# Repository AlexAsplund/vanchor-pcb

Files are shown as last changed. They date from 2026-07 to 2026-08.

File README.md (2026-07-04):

# Vanchor PCBs (helm v4.2 + thrust driver v1.1)

Carrier PCB for the [vanchor-ng](../vanchor-ng) trolling-motor autopilot:
an **Orange Pi Zero 3** (autopilot computer) + **Raspberry Pi Pico 2**
(real-time motor controller, I²C slave) on one **125×95 mm 2-layer board
(standard 1 oz)**. Thrust power lives on the companion **thrust-driver
board** cabled to J13 (any IBT-2/BTS7960-class driver also works); the
steering-servo bridge is on board. **12 V-only** (car battery, 14.4 V
charging) — the 5 V rail comes from an XL4015 buck module soldered on as a
daughterboard (U5). Full system diagrams: **`docs/architecture.md`**.

```mermaid
graph LR
    BATT[("12V battery")] -->|"J16, F1 10A, rev-FET"| VIN["VIN"]
    BATT ==>|"fat cable + ANL fuse"| TD["thrust driver board<br/>(J13 8-wire cable)"]
    VIN --> U5["U5 XL4015 buck 5V"] --> SBC["Orange Pi Zero 3 / RPi<br/>(J1 ribbon) + screen + fan"]
    VIN --> SRV["2x BTN8982TA servo bridge"] -->|"J22"| SM["12V worm servo"]
    SBC <-->|"I2C3"| PICO["Pico 2 @0x42"]
    PICO -->|"GP12-15 PWM"| TD --> M(("trolling motor"))
    PICO --> SRV
    SM -->|"AS5600, J11"| PICO
    SBC -.->|"WiFi"| TAB["tablet"]
    HWT["HWT901B AHRS"] -->|"J3 UART5"| SBC
    PICO <-->|"can2040 + J12 xcvr + J5"| N2K[("NMEA2000")]
```

*[static SVG](docs/diagrams/readme-overview.svg) — full diagram set: `docs/architecture.md`*

Cost history: v1/v2 carried an on-board 800 W H-bridge; ten documented
cost-optimization passes (see `docs/cost-optimization-log.md`) brought a
12 V build from ~$111 to **~$41 per assembled board** (~$35 parts + ~$6 PCB).
The v2 on-board-bridge design remains available at git tag/commit `bf91c4a`.

## NMEA2000 / CAN provision (helm board)

CAN lives on the Pico 2 (can2040 PIO CAN on GP18/GP19, 250 kbit/s for
NMEA2000). Plug a 3.3 V CAN transceiver module (Waveshare SN65HVD230) onto
J12 with four jumper wires: pin 1 = 3V3, pin 8 = GND, pin 6 = GP18 -> CTX,
pin 7 = GP19 -> CRX. The N2K drop cable's CAN_H/L land on the module's
screw terminal; its power/shield conductors land on J5 (V+ / GND / SHIELD).
R41 (0R, DNP): fit to power the backbone from the battery input - add an
inline 2-3 A fuse in the drop cable if you do. R42 (0R, DNP): bond shield
to GND only if the network isn't grounded elsewhere.

## Boards

- `boards/helm/` — the helm/carrier board (Orange Pi Zero 3 *or* Raspberry Pi + Pico 2, servo
  bridge, XL4015 buck daughterboard, PWM output header J13).
- `boards/thrust-driver/` — 12-24 V trolling-motor H-bridge (2-4× BTN8982TA),
  connects to helm J13 with a straight 8-wire cable. See its README for the
  base (~30 A) vs high-power (~50 A) variants and the solder-lane
  reinforcement technique.

## Repository layout

| Path | Content |
|---|---|
| `boards/helm/` | KiCad 10 project (schematic, board, custom symbols/footprints) |
| `boards/helm/sheets/*.py` | Net-spec sources — the schematic is **generated** from these |
| `boards/helm/scripts/` | Generators + gates (`build_sch.sh`, `build_board.py`, ERC/DRC helpers) |
| `boards/helm/fab/` | Gerbers, drill, BOM — upload these to PCBWay/JLCPCB |
| `boards/thrust-driver/` | Companion H-bridge board (own README, sheets, scripts, fab) |
| `docs/architecture.md` | **System diagrams**: WiFi/tablet, NMEA0183+2000, HWT901B, control loop |
| `docs/cost-optimization-log.md` | The 10 cost passes and their effect |
| `docs/superpowers/` | Design spec + implementation plan |
| `.claude/skills/` | kicad-happy review skills (vendored) |

## Regenerating the design

```sh
docker compose up -d                 # KiCad 10 container (GUI at https://localhost:3001)
./boards/helm/scripts/build_sch.sh      # specs -> .kicad_sch + ERC
docker exec vanchor-kicad kicad-cli sch export netlist --format kicadsexpr \
    -o /config/vanchor-pcb/boards/helm/vanchor-helm.net /config/vanchor-pcb/boards/helm/vanchor-helm.kicad_sch
docker exec -e BASE_GND=0 vanchor-kicad python3 /config/vanchor-pcb/boards/helm/scripts/build_board.py
# route with freerouting-1.9 (see git history for the exact docker command),
# then: docker exec vanchor-kicad python3 /config/vanchor-pcb/boards/helm/scripts/import_routes.py
```

## Connector map

| Ref | Label | Wire to |
|---|---|---|
| J16 | BATT 12V | battery + / − (board logic + servo supply; ≥1.5 mm²) |
| J13 | THRUST DRV | external driver, IBT-2 pin order: **1 RPWM · 2 LPWM · 3 R_EN · 4 L_EN · 5 R_IS · 6 L_IS · 7 VCC(5V) · 8 GND** |
| J22 | SERVO MOTOR | 12 V worm gearmotor of the steering servo |
| U5 | XL4015 BUCK | the module solders ON: pins into its 4 corner terminals, spacers, into the slotted pads (set 5.1 V first!) |
| J1 | OPI Z3 26-PIN | male header → 26-way 1:1 IDC ribbon (original-RPi style) to the Zero 3 |
| J11 | AS5600 | 4-wire cable into servo housing: 3V3 GND SDA SCL (≤1 m, twisted) |
| J3 | UART5 | **HWT901B AHRS** / GPS / NMEA0183-TTL (3V3 TTL, PH2/PH3; `uart5` overlay; wiring in `docs/architecture.md`) |
| J4 | UART2 | second serial device (PC5/PC6; enable `uart2` overlay; swap TX/RX at the JST if silent) |
| J8 | I2C3 spare | I²C sensors (bus shared with Pico link — keep short) |
| J10 | AUX 5V | fused 5 V for a screen or accessory |
| J9 | FAN + HALL | pin 1-2: 5 V fan; pin 3: **steering-zero hall switch** (A3144-class open-collector, magnet at servo center; 10 k pullup to 3V3 + RC on board, reads on Pico GP0) |
| J5 | NMEA2000 PWR | N2K drop-cable V+ / GND / SHIELD (CAN_H/L go to the transceiver module) |
| J2 | SBC2 | second SBC port: same 26-pin bus as J1, classic RPi positions — fit ONE SBC only (DNP) |
| J12 | PICO UTIL | spare Pico I/O; carries the CAN transceiver hookup (pins 1/8/6/7, see NMEA2000 section) |

Battery→motor power wiring (fat cables, ANL fuse) goes to the **thrust
driver board**, not to this board.

## Mechanical

- The Zero 3 (pre-soldered pins-up variant) connects via a **standard
  26-way 1:1 IDC ribbon** (~$1.50, original-Raspberry-Pi style) from its
  header to J1 — match pin 1 (marked) on both ends. The module mounts
  wherever suits the enclosure; the two spare M3 holes near J1 can carry a
  small mounting plate.
- The module is powered through the ribbon 5 V pins — do **not** also plug
  USB-C power. Keep the ribbon short (≤15 cm) — it carries I²C and the
  module's supply. The 3.3 V for the JST headers comes from the module's
  regulator (keep attached loads under ~200 mA total).
- J1 pins 14 & 20 and J2 pin 9 are deliberately NC (each connector keeps
  at least three other ground pins; the header escape routing owns those
  corridors).
- J2/J12 are DNP debug breakouts whose outlines slightly overlap — populate
  at most one, or use a right-angle header on J12.
- 4× M3 corner mounting holes. No heatsink needed on this board.

## Power & safety notes

- F1 (10 A mini blade) fuses everything on this board. The thrust path is
  fused externally at the battery per your driver's rating.
- **Thrust**: GP12-15 drive the external driver's RPWM/LPWM/R_EN/L_EN at
  3.3 V (fine for BTS7960-class VIH ≈ 2.5 V). 100k pull-downs on both EN pins
  keep the driver disabled when the Pico is absent/in reset. R_IS/L_IS are
  mixed (2× 1k), loaded (20k), filtered and BAT54S-clamped into Pico ADC1.
- **Servo bridge**: 2× BTN8982TA (built-in protection), fed battery-direct
  from protected VIN. Board plumbing is sized for ~5 A continuous /
  ~10 A peak servo current (F1, terminal blocks, track widths).
- Telemetry: thrust current via the driver's IS pins (ADC1), servo current
  (ADC0), battery voltage (ADC2).
- Reverse polarity: IRF9540N high-side FET; SMCJ18A TVS (12 V clamp);
  2× 470 µF/25 V bulk.
- The buck module (U5) mounts as a daughterboard: solder 4 pins into the
  XL4015's corner terminals, slide 5-8 mm spacers on, solder into the
  slotted pads (slots absorb vendor hole-grid variance; buy the common 54×23 mm module
  variant (nominal 49×18 mm hole grid) — the smaller 51×26 mm variant has a
  different grid that may not fit; verify against your module). Set 5.1 V and load-test at 4 A BEFORE
  soldering it in. R20/R21/D10/D11 sit under the module's edge — fit them
  first.
- Firmware contract: I²C slave 0x42, reg 0x00 CMD {pwm u8, dir u8, steer i8},
  reg 0x10 STATUS {angle f32, ok u8, wrap i8, state u8, vbat_mV u16,
  isense u16}; 800 ms watchdog → thrust 0, steering holds (worm self-locks).
  Pin deltas vs v2: thrust on **GP12=RPWM GP13=LPWM GP14=R_EN GP15=L_EN**;
  GP16/GP26 freed.
- Zero 3 side: I²C3 (`i2c3` overlay) for the Pico link, `uart2`/`uart5`
  overlays for the JSTs; Pico RUN on PC11, SWD reflash via PC15 (SWDIO) /
  PC14 (SWCLK) — openocd sysfsgpio/libgpiod driver on the H618.

## Bring-up checklist

1. Visual + continuity: VIN↔GND, 5V↔GND, 12V↔GND not shorted.
2. No Zero 3/Pico fitted. Feed 12 V into J16: VIN LED lights; verify the
   buck module outputs 5.0-5.2 V on J1 pins 2/4.
3. Fit the Pico only (no Zero 3): flash test firmware over USB, check I²C
   pull-ups, exercise LED_STAT.
4. Plug in the Zero 3 (pin 1 to the marked corner!). `i2cdetect -y 3` →
   device at 0x42.
5. Connect AS5600 cable: Pico reads angle; rotate servo shaft by hand.
6. Servo closed-loop test with the gearmotor on a bench supply.
7. Connect the external thrust driver to J13, small test motor on its
   outputs: verify PWM, direction, the EN failsafe (reset the Pico mid-run →
   driver must drop out) and IS telemetry on ADC1.
8. Only then wire the real trolling motor through the external driver.

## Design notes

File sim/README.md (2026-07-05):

# Analog chain simulations (ngspice)

Repeatable SPICE verification of the boards' critical analog paths.
Run: `docker run --rm -v $PWD/sim:/sim -w /sim debian:bookworm-slim sh -c "apt-get update -qq && apt-get install -y -qq ngspice gnuplot-nox && for f in *.cir; do ngspice -b $f; done && gnuplot plots.gp"`
(Digital parts — SBC, Pico, buck module, CAN — are not SPICE-able; this
suite covers every analog conditioning chain instead.)

## Results (2026-07-06, ngspice-39)

| Chain | Deck | Result | Verdict |
|---|---|---|---|
| Thrust IS telemetry (driver 1k loads → helm mix → ADC1) | `is_telemetry.cir` | 10 A → 0.21 V, 30 A → 0.63 V, 50 A → 1.05 V at the ADC (linear). **IS fault (4.4 mA): 2.10 V — inherently safe, clamp never conducts** (the mix/divider itself protects). | PASS |
| VBAT sense (47k/10k + BAT54S) | `vbat_sense.cir` | 12.6 V → 2.21 V. **40 V load-dump: ADC node clamps at 3.53 V pk** (< 3.6 V abs max), 0.42 mA into the 3V3 rail. | PASS |
| Reverse-polarity P-FET (IRF9540N + 12 V zener) | `reverse_fet.cir` | Forward 14.4 V @ 2.4 A: V(gs) −11.9 V (zener clamped), mV-class drop. **Reversed battery: load node 0 V** (fully blocked). | PASS |
| Hall zero input (10k pullup, 100n, 1k series) | `hall_input.cir` | Fall 3 µs (crisp edge for the zero index); **rise ≈ 1.3 ms** (10k·100n+cable). Fine for calibration-speed sweeps; fit C24 = 10 n if a fast index is ever needed. | PASS (note) |
| Servo IS telemetry (1k load, 10k+100n, clamp → ADC0) | `servo_is.cir` | 5 A → 0.22 V, 10 A stall → 0.44 V. Fault: 3.48 V clamped, 83 µA into 3V3. Bandwidth ≈ 160 Hz (see `servo_bw.svg`). | PASS |

Plots: `is_transfer.svg`, `vbat_dump.svg`, `hall_wave.svg`, `servo_bw.svg`.

## Firmware-relevant numbers

- ADC1 thrust scaling: **≈ 21 mV/A** at the pin (0.63 V @ 30 A) — use this,
  not a naive kILIS×1k calc (the helm mix divides by ~2.1).
- ADC0 servo scaling: **≈ 44 mV/A** (0.22 V @ 5 A).
- ADC2 battery: V(bat)·0.1754 (2.53 V @ 14.4 V).
- Hall GP0: falling edge is the index (3 µs); debounce ≥ 2 ms on release.

## Model caveats

Generic level-1 PMOS and simple diode models (BAT54/BZX85C12 parameters
approximated from datasheets). Good for topology/range verification, not
for mV-exact drops — the real IRF9540N forward drop is ~0.3 V at 2.4 A
(R_DS(on) 117 mΩ), which changes nothing qualitatively.

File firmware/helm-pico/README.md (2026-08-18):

# vanchor helm-board Pico 2 firmware

One RP2350 replaces both vanchor-ng Arduinos: **engine** (thrust, via the
companion BTN8982 driver board on J13) and **steering** (on-board BTN8982
bridge, AS5600 azimuth encoder, hall zero index) speaking the vanchor-ng
line protocol **unchanged** on two equivalent transports:

- **USB-CDC** — plug-compatible with the existing Pi stack, zero code changes.
- **I²C slave 0x42** on the SBC ribbon — the same bytes through a small
  FIFO register map, so the boat needs no USB cable. Wire spec + a complete
  Pi-side implementation guide: **`docs/I2C-TUNNEL.md`** (the Pi side needs
  one new transport class in vanchor-ng; nothing above it changes).

NMEA2000 (GP18/19) is deliberately not included yet.

## Protocol (the contract)

Vendored verbatim from vanchor-ng in `vendor/` (see `vendor/README.md`):

| Direction | Line | Notes |
|---|---|---|
| Pi → Pico | `CMD <pwm> <dir> <steer> [<seq>]*HH` | combined thrust + steering (the default) |
| Pi → Pico | `STEERD <deg> [<seq>]*HH` | v2.1 degrees-native steering |
| Pi → Pico | `THRUST <pwm> <dir> [<seq>]*HH` | split thrust channel |
| Pico → Pi | `A <angle_deg> <ok> <wrap_pct> <seq>*HH` | ~10 Hz steering feedback |
| Pico → Pi | `E <pwm> <dir> <state> <seq>*HH` | ~5 Hz engine status (`RUN/SOFTSTART/REVDELAY/FAILSAFE`) |

CRC-8 (`*HH`) on every line, both directions; CRC-less commands are rejected
(build with `-DVANCHOR_REQUIRE_CRC=0` to tolerate an old Pi). `<steer>`
±100 maps to ±180° (`STEER_FULL_SCALE_DEG`), soft endstops at ±360°
(`STEER_RANGE_DEG`) — identical numbers to `steering.ino`.

**Pi configuration**: point `motor_port` at this board's CDC device, e.g.

```yaml
hardware:
  motor_port: /dev/serial/by-id/usb-Raspberry_Pi_Pico*-if00   # Pico 2 enumerates as "Pico 2"
```

(baud is ignored on CDC; leave `steering_port`/`thrust_port` blank so the
combined `SerialMotorController` drives both axes through this one port.)

## Behaviour

- **Thrust** mirrors `engine.ino`: 1.0/s throttle slew, 1000 ms reverse
  dead-time interlock (must rest at zero before a direction flip), watchdog
  failsafe slews to zero without flipping. Output is the J13 bridge
  (GP12/13 PWM, GP14/15 enables) with the **current-adaptive PWM schedule**
  from `boards/thrust-driver/README.md`: 16 kHz when quiet, stepping down to
  2 kHz at full current (2 A hysteresis), retuned glitch-minimal.
- **Steering** mirrors `steering.ino`: same PID (6.0/0.8/0.6), deadband
  1.2°, stiction floor, stall detection (position + optional current), hold
  on watchdog loss (the worm self-locks). Feedback is the AS5600 on I2C1,
  unwrapped to a continuous multi-turn angle; the **hall index on GP0**
  re-zeros the angle absolutely every time the head passes centre — set
  `CONF enc.hall_deg` if your magnet isn't at dead-centre.
- **Safety chain**: 800 ms protocol watchdog → safe state; 2 s hardware
  watchdog → reboot; both bridges held disabled until the first valid
  command, and the board's 100 k pulldowns keep them disabled whenever the
  Pico is dead, rebooting or being reflashed.
- **Telemetry**: THR_IS / SERVO_IS / VBAT are sampled and filtered every
  tick (used for the PWM schedule and stall trip). Scale constants in
  `include/board.h` carry CALIBRATE notes — verify against a clamp meter.

## Runtime configuration (CONF)

Every tuning value in `include/board.h` below the "steering tuning" line is
a **default**, not a constant: the live values sit in a config struct you
can change over the same serial port, and optionally persist to the last
4 kB sector of the Pico's flash. Commands follow the normal line rules
(CRC-8 `*HH` suffix required unless built with `VANCHOR_REQUIRE_CRC=0`);
they do **not** feed the 800 ms motor watchdog and do not participate in
the heartbeat, so config chatter can never keep an otherwise-dead link
looking alive.

| Command | Effect |
|---|---|
| `INFO*HH` | identity / versions / health snapshot (`I ...` lines) |
| `CONF <key> <value>*HH` | set in **RAM only** — reverts on reboot |
| `CONFW <key> <value>*HH` | set in RAM **and** persist *that one key* to flash |
| `CONFSAVE*HH` | persist the **whole active config** to flash |
| `CONFDUMP*HH` | list every key: `C <key> <ram_value> <stored_value>` |

`INFO` (`INFO*58` on the wire) answers six `I` lines — firmware git version, protocol
settings, config/flash state, I²C tunnel state, uptime/VBAT/angle:

```
> INFO*58
< I fw v1.2-3-gabc123 board helm-4.2 mcu pico2*..
< I proto 2.1 crc 1 wdog 800*..
< I conf 1 keys 23 flash stored*..        ("defaults" = no valid image)
< I i2c 0x42 v1 active 0*..
< I up 7423 vbat 12.6 ang -3.2 fb 1*..
< I end 5*..
```

Replies to all of these are `C ...`/`I ...` lines (CRC'd), which the Pi's
lenient feedback parsers ignore by design:

```
> CONF steer.kp 8.5*85
< C ok steer.kp 8.5*..          RAM updated
> CONFW enc.invert 1*05
< C wrote enc.invert 1*..       RAM + flash (or "C clean" if flash already had it)
> CONFSAVE*9C
< C saved*..                    whole config written (or "C clean" — no diff)
< C err key <k> / C err range <k> / C err ratelimit / C err flash
```

Semantics worth knowing:

- **`CONFW` writes through only its own key.** The stored image is
  read-modify-written for that single key, so other *temporary* `CONF`
  experiments in RAM stay temporary. `CONFSAVE` is the opposite: it
  snapshots everything currently active.
- **Diff guard**: before any write the firmware serializes the would-be
  image and byte-compares it with the sector. Identical → no erase, no
  program, reply `C clean`. Saving an unchanged config costs zero wear.
- **Rate limit**: writes are refused (`C err ratelimit`) within 2 s of the
  previous write — a stuck script cannot chew through the flash.
- **Validation**: each key has a hard range (`src/config.h`); out-of-range
  or non-numeric values are rejected wholesale (`C err range`), never
  clamped, so a typo can't half-apply. The same validation runs when
  loading from flash, so a corrupted value can never boot into the loop.
- **Integrity**: the stored image is magic + version + count + CRC32. Any
  mismatch at boot → factory defaults (fail-safe, visible in `CONFDUMP`).
  The layout is append-only: new keys go at the end, so an image saved by
  older firmware still loads with defaults for the missing tail. A
  `CONF_VERSION` bump discards stored config entirely.

Keys (see `src/config.h` for ranges): `steer.kp/ki/kd/ilim/db/minpwm/
maxpwm/range/fullscale/stall_err/stall_move/stall_ms/stall_a/recenter`,
`enc.invert/gear/hall_deg`, `thr.slew/rev_ms/hyst_a`,
`cal.thr_vpa/srv_vpa/vbat`.

All of this works identically over the I²C tunnel — `CONF*` lines and
`C ...` replies are transport-agnostic (see `docs/I2C-TUNNEL.md` §3 for the
one nuance: drain promptly after `CONFDUMP`, its ~750 B burst is most of
the tunnel's TX FIFO).

Generating the CRC for hand-typed commands: any of the OK vectors in
`vendor/protocol_vectors.txt` shows the format; quickest is
`python3 -c "import sys;l=sys.argv[1];c=0
for ch in l.encode():
 c^=ch
 for _ in range(8):c=((c<<1)^7)&0xFF if c&0x80 else (c<<1)&0xFF
print(f'{l}*{c:02X}')" 'CONF steer.kp 8.5'` — or build the bench binary with
`VANCHOR_REQUIRE_CRC=0` and skip suffixes entirely.

### ⚠ Why writing to flash is rationed

The RP2350 executes code from external **NOR flash** (W25Q-class). That
matters twice:

1. **Wear.** NOR flash erases in 4 kB sectors and each sector is only
   rated for ~100 000 erase cycles. There is **no wear levelling** in this
   scheme — every save erases the *same* sector. 100 k sounds like a lot:
   saving once a minute, around the clock, kills the sector in ~10 weeks;
   a bug that calls `CONFSAVE` at the 10 Hz command rate destroys it in
   **under 3 hours**. Hand-tuning sessions are harmless (even 50 saves a
   day is 5+ years), but *never* automate periodic saves. The diff guard
   and the 2 s rate limit are backstops, not an invitation — a value that
   genuinely changes every save (e.g. persisting a live measurement) would
   sail straight through the diff guard. Past the rating, sectors fail as
   silent bit-rot; the CRC turns that into "boots with defaults", which is
   safe but means your calibration silently vanishes.
2. **The write stalls the firmware.** During the sector erase + program
   (tens of milliseconds) the flash chip cannot serve code, so the
   firmware runs the write from RAM with **interrupts off**: the control
   loop freezes, hall edges are missed, USB traffic queues. The PWM
   hardware keeps running at the last duty, and both watchdogs comfortably
   cover the pause, but the steering PID is open-loop for that window —
   so save at the dock, not mid-manoeuvre. A power cut exactly during the
   erase window corrupts the sector; the CRC catches it at next boot and
   you fall back to defaults (another reason `CONFDUMP`'s stored column
   exists: verify after saving).

Practical rule: tune with `CONF` (free, unlimited), persist once with
`CONFSAVE` when the boat feels right, confirm with `CONFDUMP`.

## Building

Requires the [pico-sdk](https://github.com/raspberrypi/pico-sdk) **2.0+**
(unconditionally — `pico_i2c_slave` first shipped in 2.0.0) and
`gcc-arm-none-eabi`:

```sh
export PICO_SDK_PATH=~/pico-sdk        # or -DPICO_SDK_FETCH_FROM_GIT=on
cmake -B build -DCMAKE_BUILD_TYPE=Release
cmake --build build -j
# -> build/vanchor_helm_pico.uf2 / .elf
```

CMake options: `-DPICO_BOARD=pico` targets an original RP2040 Pico (see
below); `-DVANCHOR_REQUIRE_CRC=0` builds the CRC-tolerant bench variant
(this is a real cache option wired to the compiler — no CXX_FLAGS tricks).

## Bare Pico / DIY build (no vanchor PCB)

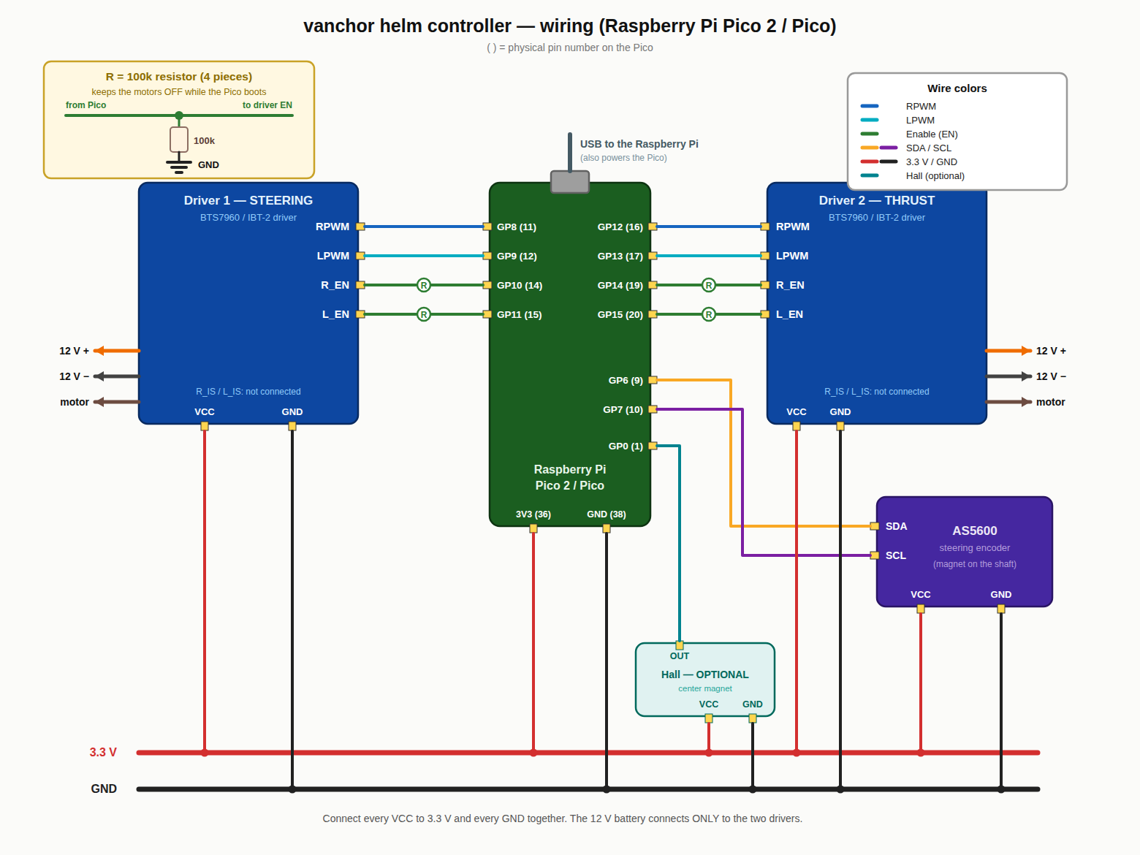
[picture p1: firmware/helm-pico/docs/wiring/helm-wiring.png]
Wiring diagram: Pico 2 with two BTS7960 drivers, AS5600 encoder and optional hall sensor


*( ) = physical pin number on the Pico. The yellow box shows how each of the
four 100 k EN pulldowns connects. Generated by
[`docs/wiring/gen_wiring.py`](docs/wiring/gen_wiring.py) — edit that, not the
image.*

The firmware runs on a plain **RP2040 Pico or Pico 2** with two IBT-2 /
BTS7960-style H-bridge modules and an AS5600 breakout — the PWM tick is
derived from `clk_sys` at boot, so both chips get correct frequencies.

```sh
cmake -B build -DPICO_BOARD=pico \
  -DCMAKE_CXX_FLAGS="-DPIN_LED_STAT=25"   # onboard LED on a bare Pico
```

Every pin and default in `include/board.h` is `#ifndef`-guarded, so override
whatever differs from the PCB the same way (`-DPIN_SRV_RPWM=2 ...`). Default
wiring (BTS7960 naming): servo bridge RPWM/LPWM = GP8/GP9, R_EN/L_EN =
GP10/GP11; thrust bridge RPWM/LPWM = GP12/GP13, R_EN/L_EN = GP14/GP15;
AS5600 SDA/SCL = GP6/GP7 (breakouts carry their own pull-ups); optional hall
zero on GP0 (internal pull-up enabled); optional SBC I2C tunnel on GP4/GP5.

Two hardware notes that the firmware cannot cover for you:

- **Add a physical ~100 k pulldown on all four EN pins.** During reset,
  BOOTSEL and reflash the Pico's pins float, and IBT-2 modules do not
  guarantee their own pulldowns — without resistors the bridges can float
  enabled while the firmware is not running. The vanchor PCB has them; a
  breadboard build must too.
- BTS7960 current sense scales differently from the PCB's BTN8982
  (kILIS ≈ 8500 vs 22700): calibrate `cal.thr_vpa` / `cal.srv_vpa` over
  serial (`CONF`) against a clamp meter, or leave current-based stall off
  (default) and skip the IS pins entirely.

## Flashing

- **First time / no debugger**: hold BOOTSEL, plug USB, copy the `.uf2`.
- **In-circuit (assembled boat)**: SWD over the ribbon from the SBC —
  SWCLK/SWDIO land on Zero 3 pins 16/18 (PC15/PC14), RUN on pin 12:
  `openocd -f interface/linuxgpiod.cfg -f target/rp2350.cfg` (`rp2040.cfg`
  for an original Pico; pin mapping in `docs/HANDOFF.md`). Never needed for
  normal operation.

## Bring-up checklist

1. Bench-power the helm board, no props, `screen /dev/ttyACM0`.
2. You should see `A ...` at 10 Hz and `E 0 F RUN -1*..` at 5 Hz. `ok` will
   be `1` only with the AS5600 magnet in range.
3. Type `CMD 0 F 0*DC` — the enables assert (bridge LEDs / 5 V on J13.7).
4. `CMD 60 F 0*..` (compute a CRC with `tests/`, or build with
   `VANCHOR_REQUIRE_CRC=0` for the bench) — thrust ramps softly; stop
   commanding — after 800 ms the `E` state shows `FAILSAFE` and it ramps out.
5. Swing the head by hand past centre — the hall edge re-zeros `A`'s angle.
6. `STEERD 10.0*..` — the servo drives; verify +deg = starboard, else send
   `CONF enc.invert 1` (encoder) and/or swap the servo motor leads (drive).

## Tests

`make -C tests` — host-compiles the **exact** shipped headers and replays
the golden `protocol_vectors.txt` through the real accept/parse path (both
CRC modes), round-trips outbound `A`/`E` CRCs, and unit-tests the reverse
gate, slew, failsafe states, PID direction/deadband/stall and the multi-turn
unwrap. CI-friendly: exits non-zero on any failure.

## Layout

```
CMakeLists.txt, pico_sdk_import.cmake   build glue (PICO_BOARD=pico2)
include/board.h                          pin map + tuning defaults
src/main.cpp                             transports, sensors, output stages
src/control_logic.h                      hardware-free control cores
src/config.h                             CONF keys, validation, persistence
src/tunnel_core.h, src/i2c_tunnel.*      I2C tunnel (register machine + glue)
src/protocol_ext.h                       THRUST token parser (+ vendored hdr)
vendor/                                  the contract, verbatim from vanchor-ng
docs/I2C-TUNNEL.md                       I2C wire spec + Pi implementation guide
tests/                                   host test suite (no SDK needed)
```

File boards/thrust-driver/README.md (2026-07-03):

# vanchor-thrust — trolling-motor DC driver

95×92 mm 2-layer board. Full H-bridge for a 12–24 V brushed trolling motor,
controlled by the vanchor-helm board over one straight 8-wire cable. Two
build variants share the same PCB:

| Variant | Fit | Continuous current |
|---|---|---|
| Base | U1 + U2 (2× BTN8982TA) | ~30 A (with cable reinforcement, see below) |
| High power | also U3 + U4 + R7 + R8 | ~50 A |

## Cable to the helm board

J1 mirrors helm J13 **pin-for-pin** — crimp a straight 8-wire cable
(0.5–1 mm², keep it under ~2 m, twist RPWM/LPWM with GND spares if longer):

| Pin | Signal | Direction |
|---|---|---|
| 1 | RPWM | helm → driver |
| 2 | LPWM | helm → driver |
| 3 | R_EN | helm → driver |
| 4 | L_EN | helm → driver |
| 5 | R_IS (current sense A) | driver → helm |
| 6 | L_IS (current sense B) | driver → helm |
| 7 | +5V (logic, from helm buck) | helm → driver |
| 8 | GND | — |

The LED (D1) lights when the helm's 5 V arrives — a quick cable check.

## Power wiring

M5 lugs: BATT+ / BATT− on the left edge, MOT A / MOT B on the right.
Use 10 mm² (8 AWG) or thicker cable for the 50 A build. **Fuse the battery
lead externally** (ANL or MIDI, 40 A base / 60 A high power) close to the
battery. There is **no reverse-polarity protection** — double-check
polarity before connecting; reversed battery destroys the BTN8982s.
D2 (SMCJ33A) clamps inductive spikes; the board is 12–24 V only.

## Solder-lane reinforcement (required above ~15 A continuous)

The board is ordered in standard 1 oz copper — cheap, but the copper alone
won't carry 30–50 A. Every power lane (VBAT band + spine, MOT A, MOT B on
top; GND band on the bottom) has an exposed solder lane (no solder mask).
Before first high-power use:

1. Clean the lanes with IPA, apply flux.
2. Tin each lane with a wide tip.
3. Lay 4–10 mm² desoldered copper braid or stripped solid wire along the
   lane and solder it down continuously end-to-end.

With braid on all lanes the base build handles ~30 A continuous, the
high-power build ~50 A. The 202 "solder mask bridge" DRC warnings are these
lanes — intentional.

## Firmware note (high-power variant)

Each BTN8982's IS pin sources I_load/kILIS (~8500). Both devices of a side
feed the **same** 1 k sense resistor, so with U3/U4 fitted the sensed
voltage per ampere stays the same only if the halves share evenly — in
practice treat the effective kILIS as ~22700 (verify datasheet 5.4.7) with U1/U2 only and ~17000 per
device (halved reading) when paralleled. Calibrate `THR_IS` scaling in the
Pico firmware after choosing the variant.

## NMEA2000 smart-node option (v1.1 provision, all DNP)

The board carries unpopulated through-hole provision to become a
standalone NMEA2000 node — same pattern as the helm board:

- **U5** Pico 2 (GP12-15 wired in parallel with J1's RPWM/LPWM/R_EN/L_EN,
  GP26/27 read the IS sense via R12/R13 1k series, GP18/19 run CAN via
  can2040 — identical GPIO map to the helm Pico, so the thrust firmware
  ports directly).
- **U6** SIP-3 5V regulator: R-78E5.0-0.5 for 12V boats; fit the wide-input
  **R-78HE5.0-0.5** on 24V boats (the plain R-78E tops out at 28V in, too
  close to a charging 24V bank).
- **J6** 4-pin CAN header: 3V3 / GND / TX / RX to a Waveshare SN65HVD230
  transceiver module; CAN_H/L go to the module's screw terminal.
- **J7** XH-3 lands the N2K drop cable's V+ / GND / SHIELD. R10 (0R DNP)
  optionally feeds the backbone from VBAT (fuse the drop cable); R11
  (0R DNP) bonds shield to GND at this node only if nowhere else does.

Dumb mode (default): populate nothing, drive via the J1 cable as before.
Smart mode: fit U5 + U6 + R12 + R13 + transceiver, **leave J1
unconnected** (both would drive the same nets), and implement a command
watchdog in the node firmware (hard-stop to neutral if the command PGN
stream halts >300-500 ms). ADC note: in normal operation the IS voltage
across the 1k loads stays under ~2.2V at 50A (kILIS 22.7k), but in FAULT
the IS pin sources mA-class current and the node's only protection is the
R12/R13 series resistance - fit them as 10k (not 1k) when populating the
node, or add BAT54S clamps to 3V3 like the helm board has.

## PWM frequency (firmware guidance)

The BTN8982TA allows up to 25 kHz, but this board fits **51 k slew-rate
resistors** (low-EMI edges, ~1.5 us each), so switching loss — not the
chip rating — sets the practical limit. Loss per edge scales with both
current and frequency; conduction loss at 30 A is only ~6 W, so high-kHz
PWM at high current quickly dominates the thermal budget:

```mermaid
xychart-beta
    title "Switching loss vs PWM frequency (13V, 51k SR edges ~3us total)"
    x-axis "PWM frequency (kHz)" [2, 4, 8, 12, 16, 20, 25]
    y-axis "watts" 0 --> 16
    line "at 30 A" [1.2, 2.3, 4.7, 7.0, 9.4, 11.7, 14.6]
    line "at 10 A" [0.4, 0.8, 1.6, 2.3, 3.1, 3.9, 4.9]
```

*[static SVG](../../docs/diagrams/pwm-loss.svg)*

**Recommended scheme: current-adaptive PWM.** Run high frequency where it
is silent *and* cheap (low current), ramp down as current rises so the
bridge stays efficient exactly when the prop is loud enough to mask the
hum:

```mermaid
xychart-beta
    title "Recommended PWM vs motor current"
    x-axis "motor current (A)" [0, 5, 10, 15, 20, 25, 30, 40, 50]
    y-axis "PWM frequency (kHz)" 0 --> 18
    line [16, 16, 12, 8, 6, 5, 4, 3, 2]
```

*[static SVG](../../docs/diagrams/pwm-schedule.svg)*

Implementation notes (RP2350, applies to the helm Pico driving this board
over J13 and to the on-board smart-node Pico alike):

- **Switch on measured current (IS), not throttle** — switching loss
  scales with amps. Use ~2 A hysteresis, or blend continuously per the
  curve above (nicer: the whine fades instead of stepping).
- **Glitch-free frequency changes**: change the PWM slice's wrap (TOP)
  value and rescale the compare level by the same ratio in the same
  update; both latch at the wrap boundary, so duty is preserved and the
  motor never feels a step.
- **Resolution is never the constraint**: 150 MHz / 16 kHz is still >13
  bits of duty resolution.
- **IS sampling**: if sampling mid-on-time, recompute the sample point
  when the wrap changes — or use the RC-averaged reading scaled by duty
  (frequency-agnostic; the helm's 20k + 100n chain does this).
- If the bridge runs warm at partial throttle, lower the 16 kHz band's
  ceiling (~10 A -> ~6 A) before touching hardware. If you truly need
  15-25 kHz at full current, swap R3/R4 (R7/R8) from 51 k to ~5.1 k —
  ~10x less switching loss, more EMI ringing; they are through-hole for
  exactly this experiment.

## Assembly order

1. SMD: BTN8982s (U1/U2, plus U3/U4 for high power), D2.
2. Resistors: R1–R6, R9 (+ R7/R8 with U3/U4), diode D1.
3. C3/C4 ceramics, C5 film, then C1/C2 electrolytics (mind polarity).
4. Lugs J2–J5, header J1.
5. Solder-lane braid (see above), then bolt to a heatsink/baseplate through
   the two M3 holes with a thermal pad under the BTN tabs for >20 A use.

## Ordering

Same fab spec as the helm board: 2 layers, 1.6 mm FR-4, 1 oz copper,
HASL, 5/5 mil, 0.3 mm min drill, tented vias. Upload
`fab/vanchor-thrust-gerbers.zip`. ~$10-15 for 5 pcs at PCBWay/JLC.

## Design notes / DRC deviations

- `solder_mask_bridge` warnings (~200): intentional exposed solder lanes.
- `pth/npth_inside_courtyard`, `courtyards_overlap`: warnings only, from
  the lug/cap density; verified manually.
- `solder_mask_bridge` is set to *ignore* in the project (the exposed
  solder lanes intentionally span nets' mask apertures).
- The routed .kicad_pcb includes hand-placed link tracks and via-hops for
  the DNP-pair nets (RPWM/LPWM/R_EN/L_EN/R_IS/L_IS between U1/U2 and
  U3/U4) — regenerating the board from `scripts/build_board.py` requires
  re-running freerouting **and** re-applying equivalent patches; treat the
  checked-in board file as the source of truth.

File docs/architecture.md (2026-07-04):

# Vanchor system architecture

How the boards, sensors, networks and the tablet fit together.
(Diagrams are Mermaid — github.com renders them in the file view.
Viewing in a commit diff, the mobile app, or a non-GitHub viewer? Use the
pre-rendered SVGs in `docs/diagrams/`, linked under each diagram.)

## System overview

```mermaid
graph TB
    subgraph BOAT["boat 12V system"]
        BATT[("12V battery")]
    end

    subgraph HELM["HELM BOARD (125x95)"]
        PWR["F1 10A + reverse-FET<br/>+ XL4015 buck 5V (U5)"]
        SBC["Orange Pi Zero 3 / RPi<br/>Linux: vanchor-ng + Signal K"]
        PICO["Pico 2 (RP2350)<br/>real-time motor ctrl, I2C 0x42"]
        SRVBR["servo H-bridge<br/>2x BTN8982TA"]
        XCVR["SN65HVD230<br/>CAN transceiver on J12"]
        PWR --> SBC
        PWR --> PICO
        SBC <-->|"I2C3 (ribbon)"| PICO
        PICO --> SRVBR
        PICO <-->|"GP18/19 can2040"| XCVR
    end

    subgraph THRUST["THRUST DRIVER (95x92)"]
        HBRIDGE["H-bridge 2-4x BTN8982TA<br/>base ~30A / high ~50A"]
    end

    TABLET["tablet / phone<br/>OpenCPN, Signal K web"]
    IMU["HWT901B AHRS<br/>(heading, roll, pitch)"]
    N2K[("NMEA2000 backbone<br/>MFD, GPS, wind, AIS")]
    N183["NMEA0183 device<br/>(GPS puck, AIS rx)"]
    SERVO["12V worm-gear servo<br/>+ AS5600 encoder"]
    MOTOR(("trolling motor"))

    BATT -->|"J16 (1.5mm2)"| PWR
    BATT ==>|"fat cable + ANL fuse"| HBRIDGE
    SBC -.->|"WiFi AP / LAN"| TABLET
    IMU -->|"J3 UART5 TTL"| SBC
    N183 -->|"J4 UART2 (TTL, see note)"| SBC
    XCVR <-->|"CAN H/L + J5 pwr/shield"| N2K
    PICO -->|"J13 -> J1 straight 8-wire"| HBRIDGE
    SRVBR -->|"J22"| SERVO
    SERVO -->|"J11 AS5600 I2C"| PICO
    HBRIDGE ==> MOTOR
```

*[static SVG](diagrams/system-overview.svg)*

Two supply domains, deliberately separate: the helm board takes a fused
1.5 mm² feed for logic + servo (≤10 A), while the motor current
(30–50 A) runs battery → thrust driver → motor on fat lugged cable and
never touches the helm board.

## Software / data flow to the tablet

```mermaid
graph LR
    subgraph SBC["SBC (Linux)"]
        SK["Signal K server"]
        VNG["vanchor-ng autopilot"]
        SK <--> VNG
    end
    subgraph PICO2["Pico 2"]
        FW["motor firmware<br/>watchdog 800ms"]
        GW["N2K gateway (core 1)<br/>can2040 + Actisense framing"]
    end

    HWT["HWT901B @ /dev/ttyAS5"] --> SK
    N183IN["NMEA0183 @ /dev/ttyAS2"] --> SK
    GW -->|"USB CDC or UART<br/>(Actisense NGT-1 emulation)"| SK
    VNG -->|"I2C 0x42: thrust/steer cmd"| FW
    FW -->|"status: angle, currents, vbat"| VNG
    SK -->|"WiFi: Signal K web, TCP 10110<br/>(NMEA0183 over IP)"| TAB["tablet: OpenCPN /<br/>Freeboard / WilhelmSK"]
```

*[static SVG](diagrams/software-dataflow.svg)*

The Zero 3's on-board WiFi runs as an access point (hostapd + dnsmasq) or
joins the boat's network; the tablet needs nothing but a browser or a
chartplotter app pointed at the Signal K/NMEA-over-TCP port.

## HWT901B attitude sensor (heading source)

The WitMotion HWT901B-TTL (9-axis AHRS + barometer, Kalman-filtered
roll/pitch/yaw) connects to **J3 (UART5)** with a 4-wire cable:

| J3 pin | Net | HWT901B pin |
|---|---|---|
| 1 | 3V3 (from SBC) | VCC (3.3–5 V) |
| 2 | UART5_TX (SBC out) | RXD |
| 3 | UART5_RX (SBC in) | TXD |
| 4 | GND | GND |

```mermaid
graph LR
    subgraph J3["helm J3 (UART5, XH-4)"]
        P1["1: 3V3"]
        P2["2: TX"]
        P3["3: RX"]
        P4["4: GND"]
    end
    subgraph HWT["HWT901B-TTL"]
        VCC["VCC"]
        RXD["RXD"]
        TXD["TXD"]
        GNDS["GND"]
    end
    P1 --- VCC
    P2 --- RXD
    P3 --- TXD
    P4 --- GNDS
```

*[static SVG](diagrams/hwt901b-wiring.svg)*

Notes: default 9600 baud (raise to 115200 with WitMotion's config tool);
enable the `uart5` DT overlay → `/dev/ttyAS5`. **Mount the sensor ≥30 cm
from the servo/thrust cables and the motor**, level, bow-aligned, and run
a magnetometer calibration after installation — heading is the autopilot's
primary feedback. Signal K ingests it via the witmotion plugin (or
vanchor-ng reads it directly).

## NMEA0183 (v2 of NMEA — serial sentences)

J3/J4 are **3.3 V TTL** UARTs. Hobby-grade GPS pucks and AIS receivers
with TTL outputs connect directly (J4 shown; enable `uart2` overlay,
`/dev/ttyAS2`; if silent, swap TX/RX at the JST — documented hedge).
A *standards-compliant* NMEA0183 device talks RS-422 differential — put a
small RS422↔TTL (or MAX3232 for RS-232 talkers) converter in the cable:

```mermaid
graph LR
    DEV["NMEA0183 talker<br/>(RS-422 A/B pair)"] --> CONV["RS422-to-TTL<br/>converter"] --> J4["helm J4<br/>UART2 TTL"] --> SK2["Signal K"]
    SK2 -->|"TCP 10110 over WiFi"| APP["tablet apps"]
```

*[static SVG](diagrams/nmea0183.svg)*

Outbound NMEA0183 (to a VHF with DSC, etc.) works the same way in
reverse; Signal K converts between 0183 sentences, N2K PGNs and its own
model, so the tablet sees one unified feed.

## NMEA2000 (v3 of NMEA — CAN bus)

CAN lives on the **Pico 2** (can2040 PIO CAN, 250 kbit/s, core 1), not on
the Linux SBC — the bus keeps its address claim and the motor watchdog
even if Linux reboots. Hardware on the helm board:

```mermaid
graph LR
    subgraph HELMN2K["helm board"]
        PICOC["Pico 2 core 1<br/>can2040 GP18/19 + NMEA2000 lib"]
        J12["J12 pins 1/8/6/7<br/>3V3 GND TX RX"]
        J5["J5: V+ / GND / SHIELD<br/>R41 0R DNP: feed bus from VIN<br/>R42 0R DNP: shield bond"]
        PICOC --- J12
    end
    MOD["SN65HVD230 module<br/>(CTX/CRX + screw terminal)"]
    J12 ---|"4 jumper wires"| MOD
    MOD ---|"CAN_H / CAN_L"| BB[("N2K backbone<br/>(terminated 2x 120R)")]
    J5 ---|"power + shield conductors"| BB
    BB --- MFD["MFD / chartplotter"]
    BB --- SRC["GPS / wind / depth / AIS"]
```

*[static SVG](diagrams/nmea2000.svg)*

The Pico emulates an **Actisense NGT-1** over USB-CDC (or a UART jumper
J4↔J12 GP0/GP1), so Signal K/canboat/OpenCPN consume the bus with zero
custom drivers. Outbound, the autopilot broadcasts heading (127250),
rudder (127245) and the standard thruster PGNs (128006–128008); anything
vanchor-specific rides proprietary PGNs.

**Future smart nodes**: the thrust driver already carries DNP provision
(Pico 2 + regulator + the same transceiver hookup on J6, N2K power on J7)
to hang directly on the backbone and take commands as proprietary PGNs —
see `boards/thrust-driver/README.md`. A dedicated servo node would reuse
the same node core.

```mermaid
graph TB
    BB2[("NMEA2000 backbone")]
    HELM2["helm board<br/>(gateway + pilot)"] --- BB2
    TD2["thrust driver v1.1<br/>smart-node option (DNP)"] -.->|"populate U5/U6 + XCVR"| BB2
    SN2["future servo node<br/>(same node core)"] -.-> BB2
    HELM2 ---|"today: 8-wire J13 cable"| TD2
```

*[static SVG](diagrams/n2k-nodes.svg)*

## Steering / thrust control loop

```mermaid
sequenceDiagram
    participant T as Tablet
    participant S as SBC (vanchor-ng)
    participant P as Pico 2
    participant D as Thrust driver
    participant V as Servo + AS5600

    T->>S: course / waypoint (WiFi)
    Note over S: PID: heading from HWT901B,<br/>position from N2K GPS
    S->>P: I2C 0x42 CMD {pwm, dir, steer}
    P->>D: RPWM/LPWM + EN (J13 cable)
    P->>V: BTN8982 bridge PWM
    V-->>P: AS5600 angle (I2C1)
    Note over P: closed-loop steer,<br/>800ms watchdog -> failsafe
    P-->>S: STATUS {angle, currents, vbat}
    S-->>T: telemetry / chart overlay
```

*[static SVG](diagrams/control-loop.svg)*

Steering zero reference: an open-collector hall switch (A3144 class) on
J9 pin 3 (with 5 V and GND on pins 1/2) sees a magnet at the servo's
center position — the Pico (GP0) uses it at boot/calibration to zero the
AS5600 angle absolutely, so the autopilot never needs a manual center
calibration after reassembly.

Failsafe chain: if the I²C command stream stops for 800 ms the Pico zeroes
thrust and holds steering (the worm gear self-locks); if the Pico resets,
100 k pulldowns on every EN pin keep both bridges disabled.

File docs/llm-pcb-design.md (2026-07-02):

# LLM PCB Design — methodology and hard-won pitfalls

How this repo's boards were designed end-to-end by an LLM agent with no
human CAD interaction: five routed, DRC-clean revisions (200×150 → 125×95)
using headless KiCad 10 + freerouting. This document is the distilled
playbook — read it before attempting changes the same way.

## Core principle: generate, don't draw

An LLM cannot see a schematic canvas or a board render usefully enough to
edit it interactively. Everything must be **text-generated and gate-checked**:

- **Schematic** = Python net-spec dicts (`sheets/*.py`: one dict per
  component: lib symbol, ref, value, footprint, pin→net map). A generator
  (`gen_sheet.py`) computes pin positions from embedded symbols and plants
  global/local labels. `.`-prefixed nets are sheet-local.
- **Board** = a placement table (`build_board.py`: ref → (x, y, rot),
  courtyard-center anchored) + zone/track primitives, regenerated from a
  skeleton string every run (never mutate incrementally — delete-loops in
  pcbnew segfault; a fresh file is deterministic).
- **Never claim a state without its gate**: ERC via
  `kicad-cli sch erc --severity-error --exit-code-violations`, a netlist
  pin-count gate (`check_nets.py` with expected min pins per critical
  net), and `kicad-cli pcb drc`. Parse the DRC report programmatically;
  the summary counts lie by omission (severity classes).

## The pipeline

```
sheets/*.py ──gen_sheet──► .kicad_sch ──ERC──► netlist ──pin-count gate──►
build_board.py (BASE_GND=0) ──placement DRC to zero──►
ExportSpecctraDSN ──freerouting 1.9 (docker+xvfb, -mp 40)──► .ses ──►
import_routes.py (SES import + GND pours + stitching vias) ──► final DRC
```

- `BASE_GND=0` omits the GND pours from the routing variant so freerouting
  routes logic-GND as tracks; the importer re-adds pours + 7 mm-grid
  stitching vias afterwards. Zone-covered nets are **invisible planes** to
  freerouting — any pad of a plane net that the pours won't reach needs a
  pre-laid stub before export.
- Iterate **placement DRC to zero** (courtyards, pads, edge) before ever
  routing. Courtyard sizes must be *measured* (`GetCourtyard().BBox()`),
  not assumed — datasheet-guessed courts caused every placement collision.

## Freerouting-specific traps (each cost a debugging session)

1. **v2.x never writes the SES** (plateau loop) — use **v1.9**, which
   needs X: run in `eclipse-temurin:21-jre` with
   `xvfb-run` + `libxext6 libxrender1 libxtst6 libxi6 libfreetype6 fontconfig`.
2. **Pre-laid vias hang v1.9's DSN preprocessing** (silent, right after
   "Multiple vias skipped"). Never put vias in the pre-route board; vias
   are fine to add *after* routing.
3. **Zero-length track segments also hang it** — guard chain-drawing
   helpers against consecutive identical points.
4. It **rounds a few µm under its clearance target**: board clearance
   0.14 mm with netclasses at 0.15 absorbs this. Expect 1–3 residual
   grazes per run anyway (lottery); they move every rerun, so fix them
   surgically, never by rerouting.
5. It threads pad channels **off-center** — the fix is recentering the
   crossing segment between the two pad edges (compute the channel from
   the measured pad positions/sizes).
6. Long (>60 mm) skinny nets get dropped nondeterministically. Pre-lay
   them as tracks along planned lanes. Design the lane set on paper first:
   nested entries (inner lane enters lower), and when two nets must cross,
   put them on opposite layers *by construction*.

## Surgical-edit discipline (the single most important lesson)

Blind coordinate edits into a routed board fail ~70 % of the time — the
field is dense and invisible. The working protocol:

1. **Probe first**: query all tracks/pads within ~2 mm of the intended
   path (`point-to-segment` distance scan). Only draw through corridors
   verified empty *on the target layer*.
2. **Move, don't redraw**: for grazes, translate the offending segment's
   endpoints (and its neighbors' shared endpoints) by the minimum vector,
   staying within ~0.2 mm of the router's choice.
3. Every fix gets an immediate full DRC; regressions are reverted, not
   patched over.
4. If three consecutive surgical attempts fail, the geometry is telling
   you something — fix the *source* (placement/lanes) and rerun the
   pipeline instead.

## KiCad scripting traps

- Footprint auto-placement by courtyard center: 1×N/2×N connector
  footprints are **vertical at rot 0** — headers almost always want 90°.
- **Socket vs header footprints mirror their pin columns** — an in-place
  footprint swap silently lands pad numbers on wrong copper. Any
  socket↔header change requires re-placement *and* re-route.
- Anchored parts (modules whose pin 1 must land exactly) need pad-vector
  auto-rotation: try all rotations, verify two pad-delta vectors; if none
  fits, the part needs flipping — this is also how a mechanically
  impossible mirror-parity arrangement announces itself.
- Zone fills fragment: same-net zones/tracks that merely touch at edges
  produce islands flagged `unconnected_items`. Make every power-pad-to-rail
  connection an **explicit track**; never rely on fill adjacency. Between
  fine-pitch connector rows there is often *no* fill at all (void math).
- Fetch `GetNetsByName()` once at script start (SWIG object decays after
  board mutations).
- DRC exclusions via `.kicad_pro` are fragile from the CLI (serialization
  format undocumented; order/position sensitive). Prefer **design-honest
  fixes**: a genuinely unreachable redundant pad becomes NC in the
  schematic with a comment, not an exclusion.
- `kicad-cli pcb drc --format json` gives item UUIDs and exact positions —
  parse this, not the text report, when automating triage.

## Domain judgment the LLM must supply itself

- Datasheet geometry from memory is unreliable — measure pads from the
  loaded footprint (the ACS758's paired power legs and the BTN8982's
  split tab were both "surprises" vs assumption).
- Copper sizing: 2 oz + zones + explicit fat tracks for >20 A;
  netclass width ≠ enforced minimum (only board `min_track_width` is).
- Keep real-time/safety functions on a microcontroller, not the Linux SBC
  (PWM jitter, watchdog); verify claimed SBC capabilities (the Zero 3
  exposes *no* hardware PWM on its header — port-mux table, not marketing).
- Cost passes work best as an explicit numbered log with per-pass deltas;
  the big wins are architectural (removing a subsystem), not component
  substitutions.
- BOM ordering reality: distributor part matching fails on formatting
  (commas, value codes like `1K0` vs `102`), MOQ traps (reel-only lines),
  and dated MPNs. Expect 3–5 iterations with the human who has cart
  visibility; encode substitution notes *in* the order file.

## What worked well / what didn't

**Worked**: generated-everything workflow; gate-driven iteration;
autorouting with generous spacing (the 2× headroom of a bigger board cut
convergence from ~10 cycles to 1–2); probe-then-edit surgery; honest
deviation notes instead of silent waivers; docker-pinned toolchain.

**Didn't**: dense hand-routing lanes computed blind (v2's driver strip
consumed more effort than the rest of the board combined — the fix was
architectural: give the router room); in-place footprint swaps; trusting
any coordinate that wasn't measured from the file.

## Addendum (2026-07-02, learned on v4.2 + thrust driver)

- **Parse DRC severity, not category counts.** `solder_mask_bridge` and
  `copper_edge_clearance` are error-class by default; grep the report for
  `; error` per block. A "0 unconnected" summary with benign-looking
  category counts can still hide real errors.
- **pcbnew silent segfaults** extend beyond footprint removal: zone
  removal and zone-outline `SetVertex` also kill the interpreter without
  saving. Same cure: staged scripts — one destructive class per process,
  `SaveBoard` immediately, verify persistence with a fresh read-only load.
- **`ZONE.GetLayerName()` lies** (returns F.Cu for B-side zones). Filter
  zones by `IsOnLayer()`/priority/bbox instead.
- **Freerouting chokes on large slotted pads** (the XL4015 daughterboard):
  runs that converged in ~7 min ran >12 min without producing a SES.
  Root-cause fixes beat rerolls: pre-lay the nets it drops, relocate
  parts that create 100 mm nets, and re-run at `-mp 25-30`.
- **Orphan pour islands**: after deleting redundant routed GND tracks,
  point-in-bbox scan each pour piece for GND items with a TH/via link —
  pieces with only SMD items need a rescue stub + via from the pad itself.
- **Nesting hand-drawn buses**: for N parallel links from a pin row to
  staggered targets, same-order pairs need the *shallower* lane on the
  net whose exit is *east* of the other's target-drop; verify every
  lane-crosses-drop pair on paper before drawing (drops span from their
  lane to the pad — any lane passing a drop's x within that span crosses).
- **Fill connects same-net tracks to zones — but only where fill exists.**
  A track "in" a zone whose channel doesn't fill (clearance-starved) ends
  dangling; prefer landing bridges on pads/vias, not on fill.

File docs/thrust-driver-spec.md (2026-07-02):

# Vanchor Thrust Driver Board — spec (v1, 2026-07-02)

Companion power board to the Helm Board: the "external IBT-2-class driver"
that helm J13 expects — now designed in-house so the pair just works.

## Requirements (user)

- Drive a 12–24 V trolling motor, fwd/rev, covering the normal thrust range
  (30 lb → 55 lb class ≈ 30–50 A max draw at 12 V).
- **Variants**: a lower-power base build and a higher-power build from the
  same PCB.
- **Direct-connect** to the helm board's J13 with a plain cable — identical
  pinout, no adapters, no firmware changes ("just work").
- Thick copper NOT required — the user reinforces the power lanes by
  soldering copper cable/braid along exposed traces.

## Design

- **Control interface J1** (1×8 pin header, *identical* to helm J13):
  `1 RPWM · 2 LPWM · 3 R_EN · 4 L_EN · 5 R_IS · 6 L_IS · 7 VCC(5V) · 8 GND`.
  A straight 8-wire cable (ribbon or Dupont) maps helm J13 pin-for-pin.
  3.3 V PWM from the Pico drives the bridges directly (VIH ≈ 2.5 V).
  100k pull-downs on R_EN/L_EN (belt-and-braces with the helm's own).
- **Bridge**: 2× **BTN8982TA** half-bridges = one full H-bridge
  (base variant, ~30 A continuous / 55 A peak with modest airflow).
  **High-power variant**: second parallel pair (U3/U4, DNP on base builds)
  — each device gets its own slew-rate resistor (51 k) and IS resistor;
  IN/INH driven common per side. Doubles thermal capacity for sustained
  ~50 A on the bigger motors.
- **Current sense**: each side's IS pin(s) into a 1 k load to GND; the tap
  goes to header pins 5/6. Scaling (kILIS ≈ 8500): 30 A → ~3.5 V, matching
  the helm's existing IS mix/divider chain into the Pico ADC.
- **Power**: BATT+ / BATT− / MOT_A / MOT_B on **M5 bolt lugs**;
  2× 2200 µF/35 V low-ESR bulk + 100 nF ceramics + 1 µF/100 V film across
  the bridge; **SMCJ33A** TVS (fits 24 V systems incl. charging, still
  protective at 12 V). External fusing at the battery (ANL, sized to motor).
- **Copper strategy** (per user): 2-layer **1 oz**, wide pours for
  VBAT/MOT_A/MOT_B/GND, plus **solder-lane mask openings** — bare-copper
  strips along each power lane so 4–10 mm² copper wire/braid can be
  soldered directly on top for the high-current builds.
- Status LED on the header's 5 V (shows the control cable is live).
- Board ≈ 80×60 mm, same generation pipeline as the helm board.

## Deliberately NOT included

- No microcontroller, no logic supply (runs entirely off the helm's
  control signals + its own battery power) — keeps it dumb and robust.
- No reverse-battery protection at these currents (a series element would
  dissipate more than the bridge); wire carefully, fuse externally.
- No thermal shutdown circuitry beyond the BTN chips' built-in protection.

## As-built deltas (v1.1, 2026-07-02)

The finished board (`boards/thrust-driver/`) deviates from this spec in:

- **Board is 95×92 mm** (not ~80×60): the extra area carries the NMEA2000
  smart-node provision — DNP Pico 2 (U5) wired in parallel with J1's
  control nets, SIP-3 5 V regulator (U6), CAN transceiver header (J6),
  N2K power/shield connector (J7) and ADC series resistors (R12/R13).
  Dumb mode (this spec) is unchanged: populate nothing, drive via J1.
- **kILIS correction**: BTN8982TA sense ratio is ~**22 700** typ (the
  8500 figure below is the BTS7960's) → 30 A ≈ 1.3 V across the 1 k
  loads, not 3.5 V. Rescale firmware telemetry accordingly.
- 4 mounting holes (2 mid-board under/near the bridge, 2 in the node
  strip), not lug-corner mounting.
- SR resistors fitted as 51 k; mask-aperture DRC check set to *ignore*
  (the solder lanes are the point). Full details: the board README.

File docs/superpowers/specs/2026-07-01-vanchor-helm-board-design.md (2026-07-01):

# Vanchor Helm Board — PCB design spec

**Date:** 2026-07-01
**Status:** approved for implementation (autonomous mode — decisions made from
vanchor-ng firmware/CAD context; alternatives documented inline)
**Reference:** `../vanchor-ng/firmware/` (protocol + engine/steering sketches),
`../vanchor-ng/cad/steering_BOM.md` (AS5600 servo unit), `vanchor.example.yaml`
(GPS/compass/motor serial devices, web UI).

## 1. Purpose

One PCB that replaces the loose-module wiring of vanchor-ng's hardware bridge:

- Carries a **Raspberry Pi 4/5** (40-pin) as the autopilot computer.
- Exposes **every GPIO UART** of the Pi on labelled connectors (GPS, compass,
  NMEA devices) plus a full 40-pin breakout.
- Hosts **one RP2350 (Pico 2) microcontroller** connected to the Pi over **I²C**
  (Pi = master, Pico = slave @ 0x42). The Pico runs both real-time jobs:
  - **Thrust**: drives an external commercial 12–48 V / 1500 W DC speed
    controller by digipot knob-hijack + a reversing contactor (exactly the
    firmware README's engine design — the 125 A path never touches this board).
  - **Steering servo**: onboard H-bridge driving the 12 V worm gearmotor of the
    custom servo, closed-loop PID on an **AS5600** encoder read over a cabled
    I²C connector.
- Powers an official **Raspberry Pi 7" DSI touchscreen** (5 V from the board;
  DSI ribbon goes straight to the Pi — no display signals cross the PCB).
- Runs from the boat battery, **12–48 V input**, with protection.

## 2. Approaches considered

**A. Motherboard-of-modules (CHOSEN).** The PCB is a 2-layer carrier that
integrates proven modules: Pi on stacking header, Pico 2 on headers, Pololu
D36V50Fx buck modules, IBT-2 (BTS7960) H-bridge module. Custom copper only for
protection, glue logic, digipot, relay driver, connectors.
*Pros:* hand-assemblable, each power part is pre-tested, replaceable after a
smoke event, matches the project's DIY style (printed gears, bought speed
controller). *Cons:* taller, slightly dearer per-unit.

**B. Fully integrated SMT (rejected for v1).** VNH5019 H-bridge, discrete 60 V
bucks, RP2350 chip on board; JLCPCB assembly.
*Pros:* compact, cheaper at volume. *Cons:* first-spin risk on the power
stages, not hand-repairable, longer design time. Sensible v2 once v1 is proven.

**C. Two-MCU split (rejected).** Mirroring the two-Nano firmware split.
The Pico 2 has two cores and plenty of pins; one I²C slave keeps the Pi-side
topology simple. Spare Pico GPIO are broken out if a second controller is ever
needed.

**On-board 1500 W bridge (rejected outright):** 125 A @ 12 V on a hobby 2-layer
board is a fire, not a feature. The firmware README's hijack approach is kept.

**REVISION (user, 2026-07-02): both drivers ON-BOARD.** The knob-hijack +
contactor concept (§4.4 below) and the off-board IBT-2 are **superseded**:

- **Thrust driver on-board**: ≥800 W @ 12 V ≈ 67 A continuous, fwd/rev,
  battery 12–48 V. Discrete H-bridge: **HIP4082IPZ** full-bridge gate driver
  (DIP-16, 80 V bus rating — covers 48 V systems incl. charging) driving
  **8× IRF100P219** (100 V, ~2 mΩ, TO-220; two per switch) with individual
  10 Ω gate resistors; single DEL resistor sets dead-time; bootstrap
  UF4007 + 1 µF per high side; 100 kΩ pull-downs on all four logic inputs and
  10 kΩ pull-up (3V3) on DIS = bridge disabled unless the Pico drives it.
  **ACS758LCB-100B** hall sensor in the battery leg for current telemetry
  (5 V out, resistively scaled + BAT54S-clamped into the Pico ADC).
  Power connections are **M5 bolt lugs** (BATT+, MOTOR A, MOTOR B, GND) —
  screw terminals don't do 70 A. 2×2200 µF/63 V bulk + film + SMCJ58A across
  the bridge. **2 oz copper**, both layers poured for the power nets.
  Thermal: ~3 W per FET at 67 A — the FET row mounts a common heatsink bar
  (clip-on, along the board edge); airflow recommended >40 A continuous.
  X9C103 digipot, PWM-DAC (MCP6002), 74AHCT125, contactor driver and the
  KNOB/CONTACTOR terminals are all deleted; the Pico drives AHI/BHI/ALI/BLI
  directly (HIP4082 VIH 2.5 V accepts 3.3 V logic).
- **Servo driver on-board**: **2× BTN8982TA** half-bridges (TO-263-7,
  hand-solderable on large pads; 40 V, protected, same RPWM/LPWM/INH/IS
  interface as the BTS7960 firmware code). VM = +12 V rail; IS pins share one
  1 kΩ sense resistor (only the active side sources), RC-filtered + clamped
  into the Pico ADC. Motor leaves on a screw terminal.
- Board grows to **150×120 mm** (power stage occupies a new 50 mm band on the
  left; everything previously placed shifts +50 mm in x).
- The single battery input is the BATT+ lug: board logic taps it *upstream*
  of the ACS758 through the existing F1 (10 A) + reverse-FET path, so board
  loads don't pollute the motor-current reading. The 70 A motor path is fused
  externally (ANL/MIDI at the battery, sized to motor).
- Battery-voltage rule: 12 V motor at 800 W needs a 12 V battery system
  (the board cannot buck 67 A). On 24–48 V systems the thrust motor must be
  rated for that system voltage. Servo motor is always 12 V (from BUCK2 —
  ≤4 A stall on 24-48 V boats — or battery-direct on 12 V boats via J17).

## 3. System architecture

```
BATTERY 12–48V ──[fuse]──[reverse-pol P-FET]──[TVS]──┬── BUCK1 5V/5A ── Pi 5V, touchscreen 5V, fan, HCT logic
                                                     └── BUCK2 12V/5A ── servo H-bridge B+, contactor coil
                                                         (jumper-bypass on 12V systems)

Raspberry Pi 4/5 (40-pin stacking header)
 ├─ I2C1 (GPIO2/3, 3.3V) ──────────────► Pico 2 I2C0 slave @0x42
 ├─ UART0/2/3/4/5 ─────────────────────► 5 labelled JST-XH headers (3V3/TX/RX/GND)
 ├─ full 40-pin breakout header
 └─ DSI + USB direct on the Pi itself (touchscreen ribbon, USB devices)

Pico 2 (RP2350)
 ├─ I2C1 master ── JST-XH cable ───────► AS5600 encoder (in servo housing)
 ├─ PWM ×2 + EN ──────────────────────► IBT-2 (BTS7960) module ──► 12V worm gearmotor
 ├─ IS ×2 ── ADC                        (current sense / stall)
 ├─ 74HCT125 (5V) ──► X9C103 digipot ──► external speed controller knob terminals
 ├─ MOSFET low-side driver ───────────► reversing DPDT contactor coil (12V)
 ├─ PWM-DAC (RC + MCP6002 @5V) ───────► alt. 0–5V throttle output (jumper-selected)
 └─ ADC ── divider ── battery voltage telemetry
```

Grounding: single common ground; battery −, external controller GND, and board
GND tie at the power-entry star point. Logic and motor returns on separate pours.

## 4. Subsystems

### 4.1 Power entry & rails
- Input 12–48 V on 5.08 mm screw terminal; **10 A blade-fuse holder** (board
  loads only: Pi+screen ≈3 A @5 V, servo ≤5 A @12 V ⇒ ≤4 A @12 V in, less at 48 V).
- Reverse polarity: P-FET high-side (100 V, e.g. SUM110P08/SQJ457EP class,
  gate zener-clamped 12 V + 100 k).
- **SMCJ58A** TVS across input after the FET; 2×470 µF/63 V bulk + 100 nF.
- **BUCK1**: Pololu **D36V50F5** module (5 V/5 A, 50 V max in) → Pi 5 V pins
  (2,4), touchscreen power connector (fused 2 A polyfuse), fan header, 74HCT125.
- **BUCK2**: Pololu **D36V50F12** module (12 V/5 A) → IBT-2 B+, contactor coil.
  On 12 V-battery boats BUCK2 is omitted and a 2-pin 5.08 mm screw-terminal
  link (rated for the 5 A servo load) bridges VIN→12 V rail instead.
- 3.3 V for Pico/AS5600 comes from the Pico's onboard regulator (VSYS←5 V).
- Note: 48 V nominal charging can exceed 50 V (buck max) — doc states 12/24/36 V
  battery systems use the modules directly; 48 V systems must be measured and,
  if >50 V, use the 60 V module variant (D36V28F5) or an external pre-regulator.

### 4.2 Raspberry Pi carrier
- 2×20 **stacking** header; Pi mounts over the board on M2.5 standoffs
  (footprint holes for Pi 4/5 pattern 58×49 mm).
- 5 V feed into pins 2/4 (bypasses USB-C; standard for embedded carriers).
- **UART headers** (JST-XH 4-pin: 3V3, TXD, RXD, GND), silkscreened with both
  GPIO numbers and Pi device names:
  | Header | GPIO | Pi 4 device | Pi 5 device |
  |---|---|---|---|
  | UART0 | 14/15 | ttyAMA0 | ttyAMA0 |
  | UART2 | 0/1 | ttyAMA2 | ttyAMA2 |
  | UART3 | 4/5 | ttyAMA3 | ttyAMA3 |
  | UART4 | 8/9 | ttyAMA4 | ttyAMA4 |
  | UART5 | 12/13 | ttyAMA5 | ttyAMA5 |
- Full 40-pin 2×20 breakout header beside the Pi (all pins pass through).
- 2-pin 5 V fan header.
- I²C1 (GPIO2/3) is the Pi↔Pico bus. The Pi has fixed 1.8 kΩ pulls on these
  pins, which is sufficient; board footprints for extra pulls are provided but
  **not populated** (avoids exceeding the 3 mA sink spec). Routed short, plus a
  spare I²C JST-XH for sensors (compass modules are often I²C).

### 4.3 Pico 2 controller
- **Pico 2 module** on 2×20 2.54 mm socket headers, USB edge accessible for
  firmware flashing (also wired: Pi GPIO → Pico RUN + BOOTSEL header pins for
  Pi-driven reflash).
- I2C0 (GP4/GP5) = slave to Pi. I2C1 (GP6/GP7) = master to AS5600 connector
  (4.7 kΩ pulls, 100 Ω series, ESD diodes near connector).
- Spare GPIO (≥8) + 3V3/GND on a utility header.

### 4.4 Thrust interface (external 1500 W controller)
- **X9C103** digipot; INC/UD/CS driven through **74HCT125** (5 V, VIH 2 V — the
  X9C at 5 V needs >3.5 V highs, which 3.3 V Pico pins can't guarantee).
- Digipot pot terminals (VH/VW/VL) on a 3-pin screw terminal → replaces the
  controller's 10 kΩ knob. 100 nF + 100 µF across wiper output per firmware BOM.
- **PWM-DAC alternative** (controllers with 0–5 V throttle input): Pico PWM →
  1 kΩ/10 µF RC → MCP6002 follower (5 V) → same terminal via solder-jumper
  selection.
- **Reversing contactor driver**: logic N-FET (IRLML6344-class) low-side, 1N4007
  flyback, 12 V coil supply from BUCK2, 2-pin screw terminal to the external
  DPDT contactor. Firmware only switches at zero throttle (existing dead-time
  logic).
- Battery-side fuse + kill switch for the 1500 W path remain **off-board** on
  the battery feed, as in the firmware README.

### 4.5 Steering servo
- **IBT-2 (BTS7960) module** plugs its 8-pin signal header into a board socket;
  its own screw terminals take B+ (12 V rail) and the gearmotor M+/M−. Module
  mounting holes align with board standoffs.
- RPWM/LPWM/R_EN/L_EN from Pico (3.3 V is within BTS7960 VIH — the IBT-2 works
  at 3.3 V logic); R_IS/L_IS → Pico ADC via divider/clamp.
- **AS5600 connector**: JST-XH 4-pin (3V3, GND, SDA, SCL) → cable into the
  servo housing (per cad/steering_BOM.md, PG7 gland). Twisted/short, 100 kHz.

### 4.6 Touchscreen
- Official RPi 7" DSI touchscreen: ribbon to the Pi's DSI port directly.
- Board provides **DISP PWR** JST-XH 2-pin (5 V, 2 A polyfuse) to the screen.
- HDMI/USB touchscreens plug into the Pi's own ports (no board support needed).

### 4.7 Telemetry & indicators
- Battery voltage divider (100 k/6.8 k + clamp) → Pico ADC.
- LEDs: VIN (after protection), 5 V, 12 V, Pico status (GPIO), Pi heartbeat
  (GPIO via 40-pin).

## 5. Firmware contract (out of scope to implement, in scope to pin-map)

The Pi↔Pico I²C register map replaces the USB `CMD` protocol; the PID/hijack
logic ports from `engine.ino`/`steering.ino`. Proposed map (documented on
schematic): 0x00 CMD {pwm u8, dir u8, steer i8}, 0x10 STATUS {angle_deg f32,
feedback_ok u8, wrap_pct i8, state u8, vbat_mV u16, i_sense u16}, watchdog
800 ms → failsafe (thrust→0, steering holds). Firmware itself lives in
vanchor-ng later; this board only fixes the pinout.

## 6. Board outline & layout intent

- **Cost guideline (user):** as cheap as possible without quality loss; cheap
  at PCBWay-class fabs. Therefore: **2-layer, ≤100 × 100 mm** (the ~$5 price
  tier), 1.6 mm FR-4, HASL, green, no castellations; track/clearance kept
  ≥0.25 mm (well above cheap-tier minimums); all parts hand-solderable
  (TH + SOT-23 only), no stencil/assembly service needed.
- The IBT-2 H-bridge module mounts **off-board** (enclosure wall) and connects
  through a 1×8 pin header + dupont/crimp cable — saves ~20 cm² of board.
- M3 corner mounts; fits a printed/off-shelf IP-rated enclosure with PG
  glands (marine). The Pi mounts over the board (stacking header + standoffs);
  only low-profile parts under it.
- Zones: power entry left edge (screw terminals), bucks beside it; Pi footprint
  right half (SD + USB/HDMI toward board edges); Pico + logic centre;
  IBT-2 + motor terminals bottom-left; low-level connectors (UARTs, AS5600,
  I²C, display power) top edge, silkscreen-labelled.
- Motor/relay currents stay in the power zone; AS5600 and I²C routes keep away
  from PWM tracks; ground pour both sides, stitched.

## 7. Deliverables

1. KiCad 10 project in this repo (`hardware/`): hierarchical schematic
   (power / pi / mcu / thrust / servo sheets), ERC-clean.
2. PCB layout, DRC-clean, with the placement zones above, routed.
3. Fab outputs: Gerbers+drill (JLCPCB naming), BOM (CSV), assembly notes.
4. `README.md`: wiring guide (battery, controller hijack, contactor, servo,
   screen), jumper table, bring-up checklist.

## 8. Risks / open items

- **48 V systems**: buck modules max 50 V — flagged in §4.1; measured battery
  voltage must be <50 V or use the alternate module.
- Pi 5 without USB-PD negotiation caps its downstream USB current — acceptable
  for GPS dongles; heavy USB loads need a powered hub.
- AS5600 cable length: keep ≤1 m at 100 kHz; if the run grows, drop bus speed
  or add a P82B96 extender (footprint not included — YAGNI).
- X9C103 wiper terminals assume the hijacked controller's knob is a plain
  10 kΩ pot at ≤5 V referenced to common ground — verify on the actual unit
  before wiring (same caveat as the firmware README).

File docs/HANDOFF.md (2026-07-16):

# Vanchor PCBs — Handoff (updated 2026-07-02)

## What this is

Two-board set for the vanchor-ng trolling-motor autopilot. System
diagrams (WiFi/tablet, NMEA0183/2000, HWT901B, servo, thrust):
**`docs/architecture.md`**.

### Helm board — rev **v4.2** (`boards/helm/`, 125×95, DRC 0/0)

- **Orange Pi Zero 3** (autopilot computer, Linux) via 26-way 1:1 IDC
  ribbon to J1 (2×13 male header); powered through the ribbon 5 V.
  **J2 = second SBC port**: same bus, classic RPi 26-pin positions — a
  Raspberry Pi (40-pin header pins 1–26) drops in instead. Fit ONE SBC.
- **Raspberry Pi Pico 2** on-board (real-time motor controller, I²C slave
  0x42 on the SBC's I²C3). PWM, AS5600 steering loop, 800 ms watchdog.
- **Thrust**: 8-wire cable from J13 to the companion thrust-driver board
  (or any IBT-2/BTS7960-class driver). Motor power never touches this board.
- **Steering servo**: on-board H-bridge, 2× BTN8982TA, protected VIN,
  ~5 A cont / 10 A peak plumbing.
- **Power**: 12 V only. J16 → F1 10 A → reverse-FET → VIN. 5 V from an
  **XL4015 module soldered on as a daughterboard (U5)**: pins + spacers
  into slotted pads; set 5.10 V and load-test at 4 A *before* soldering;
  fit R20/R21/D10/D11 (under its edge) first. Buy the 54×23 mm module
  variant.
- **NMEA2000**: can2040 on Pico GP18/19 → SN65HVD230 module jumpered to
  J12 (pins 1/8/6/7); drop-cable power/shield on J5 (R41/R42 0R options).
- **Sensors**: HWT901B AHRS on J3 (UART5); NMEA0183-TTL device on J4
  (UART2); AS5600 on J11; spare I²C on J8; fused aux 5 V (J10) + fan (J9).

### Thrust driver — rev **v1.1** (`boards/thrust-driver/`, 95×92, DRC 0/0)

- Full H-bridge, BTN8982TA: base build U1+U2 (~30 A), high-power adds
  U3/U4 + R7/R8 (~50 A). J1 mirrors helm J13 pin-for-pin.
- 1 oz copper + **exposed solder lanes** on every power lane — solder
  4–10 mm² copper braid along them for >15 A continuous (the ~200
  mask-aperture DRC hits are this feature; severity set to *ignore*).
- **NMEA2000 smart-node provision, all DNP**: Pico 2 (U5, same GPIO map
  as the helm Pico), SIP-3 5 V reg (U6 — R-78E5.0 at 12 V, R-78HE5.0 for
  24 V banks), CAN header J6, N2K power J7, ADC series R12/R13 (fit as
  10 k). Smart mode leaves J1 open. Details in its README.
- No reverse-battery protection (by design at these currents) — external
  ANL fuse, wire carefully.

## State of play

| Item | Status |
|---|---|
| Schematics | ERC 0 errors, generated from `boards/*/sheets/*.py`; netlist gates PASS |
| Boards | routed, DRC **0 errors / 0 unconnected** (severity-aware check) |
| Fab outputs | `boards/*/fab/` incl. gerber zips — upload as-is |
| Order specs | 2-layer, 1.6 mm, **1 oz**, HASL, 5/5 mil, 0.4 mm min hole, tented vias |
| Parts order | `bom/mouser-order.csv` v6 (helm); driver BOM in `boards/thrust-driver/fab/` |
| Off-Mouser | Zero 3 + XL4015 (AliExpress), Pico 2, SN65HVD230, PCBs (PCBWay) |
| Datasheet audit | 2026-07-02: all pinouts verified (BTN8982, Pico, OPi Zero 3 header vs Armbian DT dump, TVS/FET/clamp orientations). Fixes were docs-only. |

Version history (git): v1/v2 on-board 800 W bridge (`bf91c4a`), v3
external thrust driver, v3.1 12 V-only, v4 Orange Pi Zero 3, v4.1 ribbon
header, **v4.2 XL4015 daughterboard + N2K provision**; driver v1
(`258a7ac`), **v1.1 N2K node provision**. Cost log:
`docs/cost-optimization-log.md`.

## Known deviations (documented in `boards/helm/ERC-notes.md`)

- Helm J1 pins 14 & **20**, J2 pin 9: **NC by design** (escape-routing
  corridors; ≥3 ground pins remain per connector).
- J2/J12 courtyards graze 0.5 mm (both DNP; populate ≤1).
- R20/R21/D10/D11 sit inside U5's courtyard (module rides on spacers) —
  `pth_inside_courtyard` demoted to warning.
- Board clearance 0.14 mm (freerouting rounds under its 0.15 target).
- Driver: mask-aperture check *ignored* (intentional solder lanes); the
  routed `.kicad_pcb` files are **source of truth** — the build scripts
  regenerate placement but the surgical routing lives in the board files.
- Driver ERC reports 3 `pin_to_pin` errors: the paralleled BTN8982 OUT
  pins (U1‖U3, U2‖U4, high-power variant) are Power-output-to-Power-output
  by design. Waived — do not "fix".

## Open items for whoever continues

1. **Order**: PCBWay (both zips), Mouser CSV, AliExpress (Zero 3, XL4015).
   BTN line `BTN8982TAAUMA1`; 1 k = KOA `CF1/4CT52R102J`.
2. **Firmware**: WRITTEN — `firmware/helm-pico/` (Pico 2, pico-sdk). Speaks
   the vanchor-ng serial contract over USB-CDC (CMD/STEERD/THRUST in, A/E
   out, CRC-8); Pi needs only `motor_port=/dev/ttyACM0`. Host tests replay
   the golden protocol vectors. Cross-compile + flash + bring-up: its README.
   Pin map for reference: thrust GP12=RPWM GP13=LPWM GP14=R_EN
   GP15=L_EN; THR_IS GP27, SERVO_IS GP26, VBAT GP28. Runtime tuning over
   the port: CONF/CONFW/CONFSAVE. Second transport: I²C slave 0x42 on the
   ribbon tunnels the same protocol — Pi-side transport still to be added
   in vanchor-ng, full spec in `firmware/helm-pico/docs/I2C-TUNNEL.md`.
   hall zero-index input on GP0 (J9.3, 10 k pullup + RC on board; UART0 fallback pair becomes GP16/GP1). **kILIS for BTN8982TA ≈ 22 700** (not the BTS7960's 8500) — rescale
   current telemetry. SBC overlays: `i2c3`, `uart5` (HWT901B), `uart2`.
   Pico SWD via ribbon pins 16/18 (PC15/PC14, openocd `linuxgpiod`),
   RUN on pin 12 (PC11). N2K stack: ttlappalainen/NMEA2000 + can2040 on
   core 1, Actisense-NGT-1 emulation over USB to Signal K.
3. **Assembly**: bring-up checklist at the end of `README.md`; driver
   assembly + braid technique in `boards/thrust-driver/README.md`.
   Ribbon: match pin-1 marks; never plug USB-C while ribbon-powered.
4. **Marine**: conformal-coat both boards (mask connectors and the
   driver's solder lanes first — braid must be soldered before coating).
5. **UART2 TX/RX direction** on SBC pins 11/13 is unverified on real
   hardware — hedged on silk ("swap at JST if silent").

## Regenerating / changing the design

Everything is generated — never hand-edit `.kicad_sch`. For the boards,
placement + power copper regenerate from `build_board.py`, but final
routing includes surgical tracks: treat the checked-in `.kicad_pcb` as
authoritative and patch it via pcbnew scripts (playbook:
`docs/llm-pcb-design.md`).

```sh
docker compose up -d                          # KiCad 10 (GUI: https://localhost:3001)
# 1. edit boards/<b>/sheets/*.py (nets) and/or scripts/build_board.py (placement)
./boards/helm/scripts/build_sch.sh            # schematic + ERC (helm)
docker exec vanchor-kicad kicad-cli sch export netlist --format kicadsexpr \
  -o .../vanchor-helm.net .../vanchor-helm.kicad_sch
docker exec vanchor-kicad python3 .../scripts/check_nets.py .../vanchor-helm.net
docker exec -e BASE_GND=0 vanchor-kicad python3 .../scripts/build_board.py
# 2. iterate placement DRC to zero, route (freerouting-1.9 in docker + xvfb,
#    -mp 25..40), import_routes.py, DRC. Driver board: same pattern with
#    boards/thrust-driver paths.
docker run --rm -v <dir>:/work eclipse-temurin:21-jre sh -c \
  "apt-get update -qq && apt-get install -y -qq xvfb libxext6 libxrender1 \
   libxtst6 libxi6 libfreetype6 fontconfig && xvfb-run -a java -jar \
   /work/freerouting-1.9.jar -de /work/<name>.dsn -do /work/<name>.ses -mp 30"
```

The container mounts this repo at `/config/vanchor-pcb`. Freerouting 1.9
jar: re-download from GitHub releases if missing (v2.x never writes SES).
Severity-aware DRC check: parse the report for `; error` (category counts
alone mislead — mask/edge checks are error-class by default).

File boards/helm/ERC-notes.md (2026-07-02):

# ERC & DRC notes

## ERC: 0 errors

`kicad-cli sch erc --severity-error` → clean. Waived warnings:

(No waived warnings in the v4.1 two-page schematic.)

Deliberate ERC-related choices: Pico GND/AGND pins retyped passive (see
`PIN_TYPE_OVERRIDES` in `scripts/embed_symbols.py`); `+12V` needs no PWR_FLAG
(U6 VOUT drives it; with U6 DNP the net has no power-in pins); Pi I²C pull-ups
R5/R6 DNP by design. Schematic is 2 pages (carrier / control) generated
from merged net-specs; see sheets/carrier.py + control.py.

## DRC: 0 errors, 0 unconnected (v4.2 board, 2026-07-02)

The 125×95 mm v4 board (Orange Pi Zero 3 on a 26-pin socket, module on
top, low-profile parts underneath) is fully routed and passes DRC with
**zero errors and zero unconnected items**.

Documented deviations:
- `courtyards_overlap` severity set to warning: the J2/J12 DNP debug-header
  courtyards graze by 0.5 mm (the slot is 0.04 mm too small). Populate at
  most one, or fit J12 with a right-angle header. Hole-to-hole is clear.
- J1 pins 14 & 20 and J2 pin 9 are NC by design (schematic-level): the
  header escape field owns their corridors on both layers; each connector
  retains at least three ground pins.
- `pth_inside_courtyard`/`npth_inside_courtyard` demoted to warning:
  R20/R21/D10/D11 deliberately sit inside U5's courtyard — the XL4015
  daughterboard rides 5-8 mm above them on spacers.
- Clearance 0.14 mm (fab minimum 0.127): freerouting targets 0.15 exactly
  and rounds a few µm under; 0.14 absorbs that without touching the fab
  margin.

Remaining warnings (cosmetic only, waived):

| Warning | Count | Why waived |
|---|---|---|
| silk_overlap | ~19 | Reference-designator/legend text overlapping other silk; no electrical or assembly impact. |
| silk_over_copper | ~10 | Legend text clipped by exposed copper; cosmetic. |
| courtyards_overlap / pth_inside_courtyard | ~8 | J2/J12 graze + parts under the U5 daughterboard (see above). |

## Design-rule settings

- Clearance 0.15 mm (PCBWay/JLC 2-layer minimum is 0.127 mm), min track 0.25.
- Netclasses: HighCurrent 2.5 mm (VIN, ±12V, servo), Power 1.5 mm.
- **Standard 1 oz copper is fine** — battery/motor current stays on the
  external thrust driver (cost pass 10); max on-board current is the servo
  bridge + Pi supply (~10 A on VIN).

## Regeneration

Everything is scripted: `sheets/*.py` → `gen_sheet.py` (schematic) →
`build_board.py` (placement + power copper; `BASE_GND=0` for the routing
variant) → freerouting 1.9 (Docker, xvfb) → `import_routes.py` (SES import +
GND pours + stitching) → DRC. See README for the exact commands.

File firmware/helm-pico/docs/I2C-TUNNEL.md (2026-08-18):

# I²C line-protocol tunnel — wire spec + Pi implementation guide

**Audience**: whoever implements the master side in vanchor-ng. This
document is self-contained: everything the Pi needs to speak to the helm
Pico over I²C is specified here, byte by byte. The firmware side is
implemented in `src/tunnel_core.h` (register machine, host-tested in
`tests/`) and `src/i2c_tunnel.cpp` (ISR glue).

## 0. Concept

The tunnel does **not** define a new command set. It carries the exact
vanchor-ng ASCII line protocol — the same bytes that flow over the USB CDC
port, CRC-8 `*HH` framing included — through a tiny I²C register map with
two FIFOs:

```
Pi (master)                         Pico (slave 0x42)
  -- write reg 0x10 + bytes -->      RX FIFO (256 B)  --> line parser
  <-- read  reg 0x10           --    TX FIFO (1024 B) <-- A / E / C lines
```

Everything documented for the serial contract applies unchanged: `CMD`,
`STEERD`, `THRUST`, the `CONF*` family, the `A`/`E`/`C` replies, the 800 ms
watchdog, heartbeat seq semantics, CRC rules. If a line parses over USB it
parses over I²C. USB and I²C are live simultaneously; feedback is mirrored
to both, commands are accepted from both (do not drive from two places at
once — last writer wins).

## 1. Physical layer

| Item | Value |
|---|---|
| Bus | SBC ribbon I²C3: OPi Zero 3 pins 3 (SDA) / 5 (SCL) — nets `PI_SDA`/`PI_SCL` → Pico GP4/GP5 (I²C0 slave) |
| Address | **0x42** (7-bit) |
| Speed | 100 kHz or 400 kHz, master's choice (400 kHz recommended) |
| Levels | 3.3 V both ends, no level shifting |
| Pull-ups | The SBC side must provide them (the Zero 3 header does). If the bus floats, fit **R5/R6 (2.2 k, DNP)** on the helm board. The Pico enables its weak (~50 k) internal pulls only as an idle-level backstop. |
| SBC enable | `i2c3` DT overlay → `/dev/i2c-3` on the Zero 3 |
| Clock stretching | Not used by the slave in normal operation; tolerate it anyway (RP2350 hardware may stretch briefly inside a transaction). |

## 2. Register map

A write transaction's **first byte selects the register**; subsequent bytes
in the same transaction are data for that register. The register pointer
survives a STOP for the *following read* (standard write-pointer /
repeated-start-read convention). Registers `0x00–0x06` auto-increment as
they are read; `0x10` (DATA) does not.

| Reg | Name | R/W | Contents |
|---|---|---|---|
| 0x00 | `WHOAMI` | R | constant `0x56` (`'V'`) — probe/identity |
| 0x01 | `VERSION` | R | tunnel layout version, constant `0x01` |
| 0x02 | `TXA_L` | R | feedback bytes waiting, **low byte**. Reading it latches the full 16-bit count |
| 0x03 | `TXA_H` | R | high byte of the count **latched at the `TXA_L` read** |
| 0x04 | `RXF_L` | R | command-FIFO free space, low byte (latches, like TXA) |
| 0x05 | `RXF_H` | R | high byte of the latched free space |
| 0x06 | `FLAGS` | R | bit0 = RX overflow, bit1 = TX overflow. **Clears on read** |
| 0x10 | `DATA` | R/W | the FIFO. Write: command bytes in. Read: feedback bytes out; `0x00` filler when empty |
| other | — | — | read as `0x00`; writes ignored |

Rules that matter:

- **Always read `TXA_L` before `TXA_H`** (one 2-byte read starting at 0x02
  does this naturally via auto-increment). `TXA_H` alone returns whatever
  was last latched.
- Registers other than `DATA` are **read-only**; writing data bytes to
  them is silently ignored (verified by the firmware test suite).
- `DATA` reads never auto-increment — you can drain any number of bytes in
  one transaction starting at 0x10.
- Filler: reading `DATA` past the available count returns `0x00`. ASCII
  lines never contain `0x00`, so a master that over-reads can simply strip
  NULs. The clean pattern is: read the count, then read exactly that many.

## 3. Stream semantics

- **Commands (Pi → Pico)** are raw line-protocol bytes: the full line
  including the `*HH` CRC and a terminating `\n` (`\r\n` also fine). A line
  MAY be split across multiple write transactions ("CMD 0 " then
  "F 0*DC\n") — bytes accumulate until the newline. Don't interleave two
  half-lines; there is one stream.
- **Feedback (Pico → Pi)** is whole `\r\n`-terminated lines: `A …` at
  ~10 Hz, `E …` at ~5 Hz, `C …` replies to `CONF*` commands. The firmware
  queues a line **all-or-nothing**: if the TX FIFO can't hold the entire
  line it is dropped and the TX-overflow flag is set — the master never
  sees a truncated line. (Even if it somehow did, the line CRC rejects it;
  keep verifying CRCs exactly like the serial driver does.)
- **Idle gating**: the Pico only queues feedback after it has seen a master
  transaction within the last **3 s**. First contact (any read, e.g. a
  WHOAMI probe) opens the tap; a master that stops polling for 3 s stops
  accumulating stale telemetry. Consequence: after (re)connecting, expect
  the first `A`/`E` lines to appear within ~100–200 ms of your first poll,
  not instantly.
- **Overflow behaviour**: RX full → excess command bytes are dropped and
  flagged; the mutilated line fails CRC/parse and the watchdog covers the
  gap (same degradation path as serial noise). TX full → whole feedback
  lines dropped, flagged. Poll `FLAGS` occasionally and log a warning when
  nonzero — in a healthy 10 Hz loop both flags stay 0 forever.
- **Sizing**: worst-case steady state is ~37 B per poll cycle at 10 Hz
  (one 25 B `A` line + half of a 22 B `E` line). A `CONFDUMP` burst is
  ~24 lines ≈ 750 B — under the 1024 B TX FIFO, but drain promptly (or
  dump while the motor loop is otherwise quiet).

## 4. Canonical master session (byte level)

Probe:
```
W 0x42: [0x00]            # set pointer to WHOAMI
R 0x42: [0x56, 0x01]      # WHOAMI, then VERSION via auto-increment
```

Send a command (one transaction):
```
W 0x42: [0x10, 'C','M','D',' ','0',' ','F',' ','0','*','D','C','\n']
```

Poll + drain feedback:
```
W 0x42: [0x02]            # pointer to TXA_L
R 0x42: [n_lo, n_hi]      # bytes available (latched pair)
if n > 0:
    W 0x42: [0x10]        # pointer to DATA
    R 0x42: n bytes       # exact drain; split into chunks if you like
```

Health check (optional, each few seconds):
```
W 0x42: [0x06]; R 0x42: [flags]   # nonzero -> log; flags auto-clear
```

`i2c-tools` bench equivalents (bus 3):
```sh
i2cdetect -y 3                               # shows 0x42
i2ctransfer -y 3 w1@0x42 0x00 r2             # 0x56 0x01
python3 - <<'EOF'                            # full round-trip
from smbus2 import SMBus, i2c_msg
import time
with SMBus(3) as bus:
    bus.i2c_rdwr(i2c_msg.write(0x42, b"\x10CMD 0 F 0*DC\n"))
    time.sleep(0.15)
    bus.i2c_rdwr(i2c_msg.write(0x42, b"\x02"))
    rd = i2c_msg.read(0x42, 2); bus.i2c_rdwr(rd)
    n = int.from_bytes(bytes(rd), "little")
    bus.i2c_rdwr(i2c_msg.write(0x42, b"\x10"))
    rd = i2c_msg.read(0x42, n); bus.i2c_rdwr(rd)
    print(bytes(rd).decode())                # A ...*HH \r\n E ...*HH
EOF
```
Use `i2c_msg`/`i2c_rdwr` (raw I²C), not the SMBus block calls — SMBus caps
transactions at 32 bytes and inserts a count byte the tunnel doesn't use.

## 5. Implementing the Pi side in vanchor-ng

The whole point: **do not touch `SerialMotorController` or the protocol
code.** Implement one new transport and let the existing stack run over it.

`src/vanchor/hardware/serial_link.py` defines the ABC every driver uses:

```python
class SerialTransport(abc.ABC):
    async def open(self) -> None
    async def close(self) -> None
    async def read_line(self) -> str      # one line, newline stripped
    async def write_line(self, line: str) -> None
    async def read(self, n: int = 4096) -> bytes
    async def write(self, data: bytes) -> None
```

Suggested `I2cTransport(SerialTransport)` (new file, e.g.
`src/vanchor/hardware/i2c_link.py`):

- **ctor** `(bus: int, addr: int = 0x42, poll_hz: float = 20.0)`.
- **open()**: open `/dev/i2c-<bus>` (smbus2 `SMBus`), probe WHOAMI==0x56
  and VERSION==0x01, raise on mismatch (that's what makes the supervisor's
  reconnect/backoff loop work unchanged). Start an internal poll task.
- **poll task** (the only I²C-specific logic): every `1/poll_hz`
  seconds — read `TXA` (2 bytes at 0x02), if nonzero read that many bytes
  at 0x10, append to a `bytearray`, split on `\n`, push complete lines
  (rstrip `\r`) into an `asyncio.Queue`. Every ~5 s read `FLAGS` (0x06)
  and log a rate-limited warning when nonzero.
- **read_line()**: `await queue.get()` — the read-supervisor and the
  CRC/parse layers above need nothing else. On a persistent bus error
  raise `EOFError` so `_SerialReadSupervisor` reconnects exactly as it
  does for a yanked USB cable.
- **write_line(line)**: one `i2c_rdwr` write of `b"\x10" + line.encode() +
  b"\r\n"`. Lines are ≤48 bytes, so a single transaction always suffices.
  Serialize writes with the poll task via an `asyncio.Lock` around bus
  access (SMBus handles are not concurrency-safe); run the *blocking*
  smbus2 calls in `asyncio.to_thread` / an executor, mirroring how
  `PySerialTransport` keeps the event loop clean.
- **read()/write()**: byte-level passthroughs of the same FIFOs (the ABC
  requires them; the motor driver doesn't use them).

Config plumbing suggestion (keeps today's semantics): accept an
`i2c:<bus>:<addr>` scheme in the existing `motor_port` field, e.g.
`motor_port: "i2c:3:0x42"`, and have the transport factory pick
`I2cTransport` for that scheme and `PySerialTransport` otherwise. Baud and
the serial framing knobs are simply ignored for I²C. Everything above the
transport — combined controller, heartbeat, health flags, telemetry — runs
byte-identically.

Timing sanity: at 400 kHz a 32-byte transaction is ~1 ms; the 20 Hz poll +
10 Hz command cadence uses well under 5 % of the bus. Don't poll faster
than ~50 Hz — it buys nothing and each transaction interrupts the Pico
briefly (the ISR is a few µs per byte; the control loop tolerates it, but
there's no reason to hammer it).

> **CONFSAVE stall**: persisting config runs a flash erase with IRQs off
> for tens of ms — the slave does not ACK during that window and an in-flight
> master transaction can error. The Pi transport tolerates it (it takes 5
> consecutive poll errors to declare the link dead), but avoid CONFSAVE
> mid-manoeuvre.

## 6. Failure modes & edge cases (read before coding)

| Situation | What happens | Master's job |
|---|---|---|
| Pico rebooting / SWD reflash | address NAKs | treat as transport error → supervisor backoff-reconnect (probe WHOAMI on reopen) |
| Master stops polling ≥3 s | tunnel goes idle, TX queueing stops (no stale backlog) | nothing; resume polling, fresh lines appear |
| TX FIFO overflow (master too slow) | whole lines dropped, bit1 of FLAGS | drain faster / log; never partial lines |
| RX FIFO overflow (writer runaway) | bytes dropped, bit0 of FLAGS; broken line fails CRC | back off; watchdog already covers the gap |
| Over-read of DATA | `0x00` filler | strip NULs or read exact counts |
| Noise/corruption on the bus | line CRC fails → line ignored (both directions) | identical to serial: reject, never guess |
| Both USB and I²C connected | both accept commands, both get feedback | don't drive from two controllers at once |
| Command watchdog | I²C commands feed the same 800 ms watchdog | keep the 10 Hz `CMD` cadence, same as serial |

## 7. Compliance checklist for the Pi implementation

- [ ] WHOAMI/VERSION probed on open; mismatch = failed open.
- [ ] `TXA_L` before `TXA_H` (single 2-byte read at 0x02).
- [ ] Raw-I²C transfers (`i2c_rdwr`), not 32-byte-capped SMBus block ops.
- [ ] CRC appended on every outbound line; CRC verified on every inbound
      line (reuse `append_crc` / `strip_verify_crc` — zero new code).
- [ ] `EOFError` on persistent bus failure so the existing supervisor
      reconnects.
- [ ] FLAGS polled occasionally; overflows logged, never fatal.
- [ ] Bench-verified against real firmware with the session in §4 before
      boat deployment (the same BENCH-VERIFY discipline as
      `serial_channels.py`).

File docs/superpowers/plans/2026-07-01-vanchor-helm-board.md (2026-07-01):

# Vanchor Helm Board Implementation Plan

> **For agentic workers:** REQUIRED SUB-SKILL: Use superpowers:subagent-driven-development (recommended) or superpowers:executing-plans to implement this plan task-by-task. Steps use checkbox (`- [ ]`) syntax for tracking.

**Goal:** A complete, fab-ready KiCad 10 project for the Vanchor Helm Board — Pi 4/5 carrier + Pico 2 I²C slave controlling an external 1500 W speed controller (digipot hijack + reversing contactor) and an onboard-driven 12 V servo (IBT-2 module, AS5600 feedback), all UARTs broken out, 12–48 V input.

**Architecture:** Hierarchical schematic (root + 5 sheets: power, pi, mcu, thrust, servo) hand-authored as `.kicad_sch` s-expressions; PCB generated by a Python script running against the container's `pcbnew` (footprint load, net assign, placement, pours), then routed (scripted power routing + freerouting for signals, fallback scripted manhattan), validated with `kicad-cli` ERC/DRC.

**Tech Stack:** KiCad 10.0.3 in the `vanchor-kicad` docker container (`docker exec vanchor-kicad kicad-cli …`; project visible at `/config/vanchor-pcb`), Python 3 + pcbnew inside the container.

## Global Constraints

- All files live under `/home/alex/projects/vanchor-pcb` (editing outside the project is prohibited; vanchor-ng is read-only reference).
- KiCad file format: 10.x (`(version 20250114)` era as emitted by the container's KiCad; when in doubt, generate a scratch file with the GUI-less CLI or copy headers from a `kicad-cli`-created file).
- Verification gates (the "tests" of this plan): `docker exec vanchor-kicad kicad-cli sch erc --exit-code-violations --severity-error …` and `… pcb drc --exit-code-violations --severity-error …` must exit 0.
- Commit after every task with a `feat:`/`chore:` message + Claude trailer.
- Hardware "test-first" adaptation: for each sheet, the ERC run BEFORE authoring must fail (file absent/unwired), then pass after — recorded in the task log. Full code blocks for `.kicad_sch` are impractical in-plan; the **net tables below are the authoritative content** and the sheet must implement them exactly.

## Authoritative net map

Rails: `VIN_RAW` (post-fuse), `VIN` (post P-FET, TVS'd), `+12V`, `+5V`, `+3V3` (from Pico 3V3_OUT), `GND` (single).

### Power sheet (`power.kicad_sch`)
| Ref | Part / footprint | Connections |
|---|---|---|
| J16 | Screw terminal 2P 5.08 | 1=BATT+ → F1.1, 2=GND |
| F1 | Blade fuse holder (10 A) | 1←J16.1, 2=VIN_RAW |
| Q1 | IRF9540N TO-220 | D=VIN_RAW, S=VIN, G→R1 |
| R1 | 47k 0.25W | Q1.G → GND |
| D4 | BZX85C12 zener | A=Q1.G, K=Q1.S (Vgs clamp) |
| D5 | SMCJ58A (SMC) | VIN → GND |
| C1,C2 | 470 µF/63 V radial | VIN → GND |
| U5 | D36V50F5 module (2×6 0.1" grid) | VIN=VIN, GND=GND, VOUT=+5V, EN n/c, PG n/c, VRP n/c |
| U6 | D36V50F12 module (same fp; DNP on 12 V boats) | VIN=VIN, VOUT=+12V |
| J17 | Screw terminal 2P 5.08 ("12V LINK") | 1=VIN, 2=+12V (bridged on 12 V boats) |
| C3 | 100 µF/10 V | +5V → GND |
| C4 | 100 µF/25 V | +12V → GND |
| LED1+R2 | green + 15k 0.5W | VIN → GND |
| LED2+R3 | green + 1k | +5V → GND |
| LED3+R4 | green + 4.7k | +12V → GND |

### Pi sheet (`pi.kicad_sch`)
J1 = 2×20 stacking header (Pi mounts on top). J2 = 2×20 breakout header, all 40 pins paralleled with J1.
| J1 pin | Net | | J1 pin | Net |
|---|---|---|---|---|
| 1,17 | 3V3_PI | | 2,4 | +5V |
| 3 | PI_SDA | | 5 | PI_SCL |
| 6,9,14,20,25,30,34,39 | GND | | 7 | UART3_TX (GPIO4) |
| 29 | UART3_RX (GPIO5) | | 8 | UART0_TX (GPIO14) |
| 10 | UART0_RX (GPIO15) | | 27 | UART2_TX (GPIO0) |
| 28 | UART2_RX (GPIO1) | | 24 | UART4_TX (GPIO8) |
| 21 | UART4_RX (GPIO9) | | 32 | UART5_TX (GPIO12) |
| 33 | UART5_RX (GPIO13) | | 11 | PI_PICO_RUN (GPIO17) |
| 37 | PI_LED (GPIO26) | | rest | pass-through to J2 only |

- J3..J7 = UART0/2/3/4/5 JST-XH 4P: 1=3V3_PI, 2=TX, 3=RX, 4=GND. Silk: device names (ttyAMA0/2/3/4/5).
- J8 = spare I²C JST-XH 4P: 3V3_PI/PI_SDA/PI_SCL/GND. R5,R6 = 2.2k footprints PI_SDA/PI_SCL→3V3_PI, **DNP**.
- J9 = fan 2P: +5V/GND. J10 = DISP PWR JST-XH 2P: F2 (polyfuse 2A) +5V→DISP_5V, GND.
- LED4+R7 (1k): PI_LED→GND.

### MCU sheet (`mcu.kicad_sch`)
U1 = Pico 2 on 2×20 socket. GND pins 3,8,13,18,23,28,38; AGND 33.
| Pico pin | GP | Net |
|---|---|---|
| 6/7 | GP4/GP5 | PI_SDA / PI_SCL (I2C0 slave) |
| 9/10 | GP6/GP7 | ENC_SDA / ENC_SCL (I2C1 master) |
| 11/12 | GP8/GP9 | RPWM / LPWM |
| 14/15 | GP10/GP11 | R_EN / L_EN |
| 16/17 | GP12/GP13 | DP_INC_3 / DP_UD_3 |
| 19/20 | GP14/GP15 | DP_CS_3 / THR_PWM_3 |
| 21/22 | GP16/GP17 | CONT_GATE_3 / LED_STAT |
| 31/32/34 | GP26/27/28 | ISENSE_R / ISENSE_L / VBAT_SENSE |
| 30 | RUN | ←R8 1k← PI_PICO_RUN |
| 36 | 3V3_OUT | +3V3 |
| 39 | VSYS | +5V |
| 24,25,26,27,29,1,2,4,5 | GP18..22, GP0..3 | J12 utility header (+3V3, GND incl.) |

- R9/R10 = 4.7k ENC_SDA/ENC_SCL → +3V3.
- Battery telemetry: R11 100k VIN→VBAT_SENSE, R12 6.8k VBAT_SENSE→GND, C5 100n, D6 BAT54S clamp to +3V3.
- LED5+R13 (1k): LED_STAT→GND.

### Thrust sheet (`thrust.kicad_sch`)
- U2 = 74HCT125 DIP-14, VCC=+5V (C6 100n). 1OE/2OE/3OE/4OE (1,4,10,13)=GND. 1A(2)=DP_INC_3→1Y(3)=DP_INC_5; 2A(5)=DP_UD_3→2Y(6)=DP_UD_5; 3A(9)=DP_CS_3→3Y(8)=DP_CS_5; 4A(12)=THR_PWM_3→4Y(11)=THR_PWM_5.
- U3 = X9C103 DIP-8: 1=INC←DP_INC_5, 2=U/D←DP_UD_5, 7=CS̄←DP_CS_5 + R14 10k pull-up to +5V, 8=VCC=+5V (C7 100n), 4=VSS=GND, 3=VH→J13.1, 5=RW→JP1.A, 6=VL→J13.3.
- PWM-DAC: THR_PWM_5 →R15 1k→ node THR_ANA (C8 10 µF→GND) → U4A MCP6002 follower (V+=+5V C9 100n, inA+=THR_ANA, inA−=outA, outA→JP1.B). U4B tied off (inB+=GND, inB−=outB).
- JP1 = 3-pad solder jumper: A=RW, B=outA, C(common)→J13.2 (WIPER) + C10 100n & C11 100 µF →GND.
- J13 = screw 3P "KNOB": 1=VH, 2=WIPER, 3=VL.
- Contactor: Q2 IRLZ44N TO-220: G←R16 100Ω←CONT_GATE_3 + R17 100k→GND; D→J14.2; S→GND. J14 = screw 2P "CONTACTOR": 1=+12V, 2=Q2.D. D7 1N4007: A=J14.2, K=J14.1.

### Servo sheet (`servo.kicad_sch`)
- J15 = 1×8 pin header "IBT-2" (module mounts off-board, cabled): 1=RPWM, 2=LPWM, 3=R_EN, 4=L_EN, 5=R_IS→R18 10k→ISENSE_R (D8 BAT54S clamp +3V3, C12 100n), 6=L_IS→R19 10k→ISENSE_L (D9 clamp, C13 100n), 7=+5V, 8=GND.
- J11 = JST-XH 4P "AS5600": 1=+3V3, 2=GND, 3←R20 100Ω←ENC_SDA, 4←R21 100Ω←ENC_SCL. D10,D11 BAT54S ESD near connector.

### Root (`vanchor-helm.kicad_sch`)
Five sheet symbols; power flags (PWR_FLAG on VIN_RAW, GND, +5V, +12V, +3V3, 3V3_PI); title block.

---

### Task 1: Project bootstrap + toolchain gate

**Files:** Create `hardware/vanchor-helm.kicad_pro`, `hardware/vanchor-helm.kicad_sch` (minimal empty), `hardware/vanchor-helm.kicad_pcb` (minimal), `.gitignore` (backups, `-cache/`, `fp-info-cache`).

- [ ] Author minimal project trio (copy header conventions KiCad 10 emits).
- [ ] Gate: `docker exec vanchor-kicad kicad-cli sch erc --exit-code-violations -o /tmp/erc.rpt /config/vanchor-pcb/hardware/vanchor-helm.kicad_sch` → exit 0 on empty sch.
- [ ] Gate: same for `pcb drc`. Record both exit codes.
- [ ] Commit `chore: bootstrap KiCad project skeleton`.

### Task 2: Project symbol library

**Files:** Create `hardware/vanchor-helm-lib.kicad_sym`; register in `sym-lib-table`.

**Produces:** symbols `Pico2` (40-pin module), `D36V50Fx` (module, 6 logical pins), `X9C103`, `IBT2_Header` (8 pins), `IRF9540N`/`IRLZ44N` (reuse Device:Q_PMOS/NMOS_GDS), plus standard symbols referenced from container libs (`Device:R,C,CP,LED,D,D_Zener,D_TVS,D_Schottky_Dual_A2KK? (BAT54S=Diode:BAT54S)`, `Connector_Generic:Conn_01x02/03/04/08`, `Connector_Generic:Conn_02x20_Odd_Even`, `74xx:74HCT125? (container lib name: 74xx:74LS125 variants — use 74xx:74HCT125 if present else define)`, `Amplifier_Operational:MCP6002-xP`, `Jumper:SolderJumper_3_Open`, `power:+5V,+12V,+3V3,GND,PWR_FLAG` + custom `VIN`,`3V3_PI`).
- [ ] Check which standard symbols exist: `docker exec vanchor-kicad python3 -c` grep of `/usr/share/kicad/symbols`.
- [ ] Author custom symbols; embed/copy standard ones into project lib so schematic is self-contained.
- [ ] Gate: load lib via a scratch schematic referencing every symbol; `kicad-cli sch erc` parses (exit 0/only-warnings).
- [ ] Commit `feat: project symbol library`.

### Tasks 3–7: Author sheets (power, pi, mcu, thrust, servo — one task each)

Implement the net tables above exactly, one `.kicad_sch` per task, wired with labels (global labels for inter-sheet rails/nets, hierarchical pins optional — global labels acceptable given single instance of each sheet).
- [ ] Per task gate (before): ERC on root referencing the new sheet fails/reports missing.
- [ ] Per task gate (after): `kicad-cli sch erc --exit-code-violations` on the sheet-integrated project → 0 errors (warnings reviewed and either fixed or waived in `hardware/ERC-notes.md` with justification).
- [ ] Commit per sheet `feat: <sheet> schematic`.

### Task 8: Root sheet integration + full ERC

- [ ] Root sheet with 5 sheet instances, PWR_FLAGs, title block.
- [ ] Gate: full-project ERC exit 0; `kicad-cli sch export netlist` succeeds; net count sanity: every net in the tables present (script `hardware/scripts/check_nets.py` compares netlist to a checked-in expected-nets list).
- [ ] Commit `feat: root schematic, ERC clean`.

### Task 9: Footprint assignment + board generation

**Files:** Create `hardware/scripts/build_board.py` (runs in container against pcbnew), `hardware/footprints.pretty/` for customs (D36V50Fx 2×6, IBT-2 socket+mount, solder jumper if absent).

Footprints (assign as symbol properties in schematics): TO-220 vertical (Q1,Q2), DIP-8/14 sockets (U2,U3,U4), radial CP 10×12.5 (C1,C2), SMC (D5), DO-41 (D4,D7), 0805 for R/C/LEDs? — **through-hole preferred for hand build**: R=Axial_DIN0207, C=Disc_D5, LED=D5.0mm, BAT54S=SOT-23 (SMD unavoidable, fine), polyfuse radial, JST XH side-entry, screw terminals 5.08, fuse holder Keystone 3557, 2×20 headers.
- [ ] Verify D36V50Fx physical dimensions (WebFetch Pololu dimension diagram) before authoring its footprint; row spacing recorded in `hardware/docs/module-pinouts.md`.
- [ ] `build_board.py`: import netlist, place per zones — **outline 100×100 mm** (PCBWay/JLC cheap tier; grow to 100×120 only if unroutable), power entry left edge, Pi hole pattern (58×49) right half with Pi overhanging the right board edge (allowed — Pi is above the board on standoffs; only low-profile/SMD parts and side-entry JST under it), Pico centre-left, thrust DIPs bottom-centre, top edge connector row (UARTs, I²C, AS5600, DISP, fan, IBT-2 header); M3 corner holes; GND pour both layers, +5V/+12V/VIN pour islands top in power zone.
- [ ] Gate: `kicad-cli pcb drc` → unrouted-net violations expected (recorded count), zero footprint/courtyard errors.
- [ ] Commit `feat: board generation, placement, pours`.

### Task 10: Routing

- [ ] Scripted power routing: VIN/+12V/GND fat traces (4 mm) + pour connections; 5V feed to Pi 2 mm.
- [ ] Signal routing: try freerouting (install headless jar + JRE inside container via apt/curl; `kicad-cli pcb export specctra` if available in 10.0 — verify; import `.ses` via pcbnew `ImportSpecctraSES`). Fallback: scripted manhattan routing per net class.
- [ ] Gate: `kicad-cli pcb drc --exit-code-violations --severity-error` → 0 errors, 0 unrouted.
- [ ] Commit `feat: routed board, DRC clean`.

### Task 11: Fab outputs + docs

- [ ] `kicad-cli pcb export gerbers/drill/pos`, `sch export bom --format csv`, `sch export pdf`, `pcb render` (top/bottom PNG for README) into `hardware/fab/` (gerbers zipped, JLCPCB layer naming).
- [ ] `README.md`: system overview, wiring guide (battery, knob-hijack, contactor, servo, AS5600, screen), jumper table (JP1 wiper source, J17 12V link, DNP table for 12 V boats), UART header map, bring-up checklist, firmware register map from spec §5.
- [ ] Gate: gerber zip contains ≥ 8 layers/files; README renders; final `git status` clean after commit.
- [ ] Commit `feat: fab outputs and documentation`.

## Self-Review (done at write time)

1. **Spec coverage:** power §4.1→T3, Pi/UARTs/display §4.2+4.6→T4, Pico §4.3→T5, thrust §4.4→T6, servo/AS5600 §4.5→T7, telemetry §4.7→T5/T3 LEDs, deliverables §7→T8–T11. Firmware map §5 → README task. ✓
2. **Placeholders:** none — net tables are exact; two verify-at-execution items (D36V50Fx row spacing, 74HCT125 lib symbol name, specctra export availability) are explicit verification steps, not gaps. ✓
3. **Consistency:** net names cross-checked between sheets (DP_*_3/5, ISENSE_*, ENC_*, PI_*, THR_*). Pico pin numbers vs GP map checked. ✓

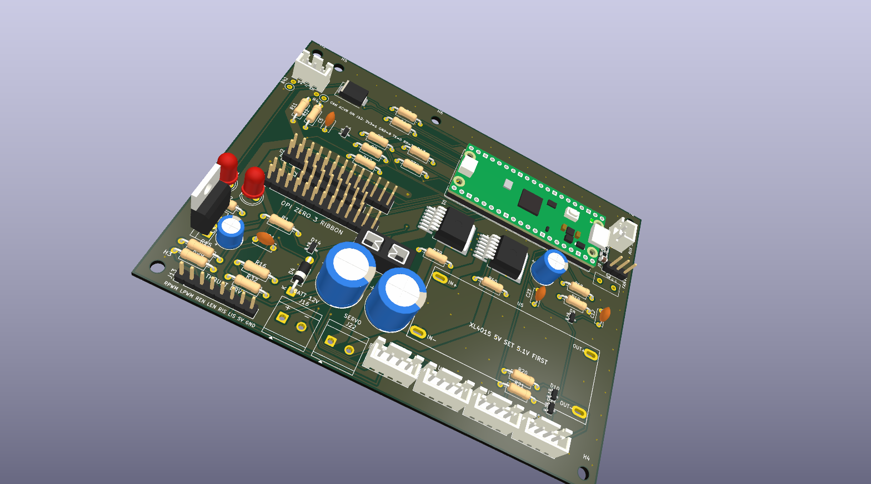
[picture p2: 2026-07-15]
boards/helm/fab/renders/board-3d.png

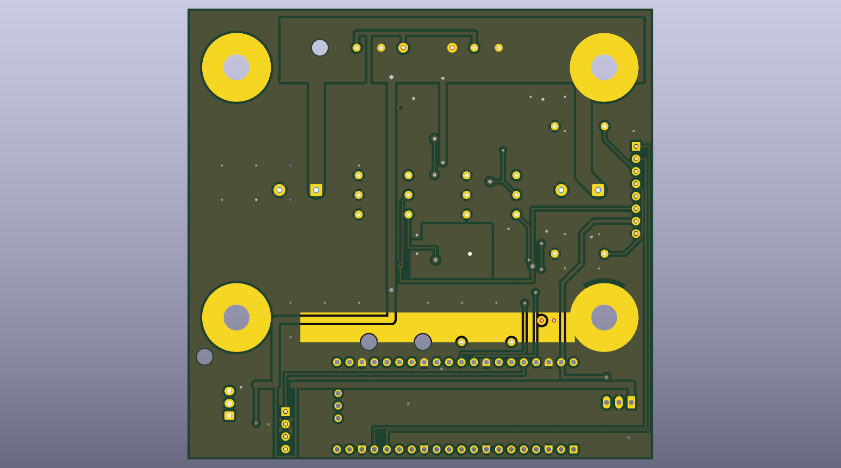
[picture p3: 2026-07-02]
boards/thrust-driver/fab/renders/board-bottom.png

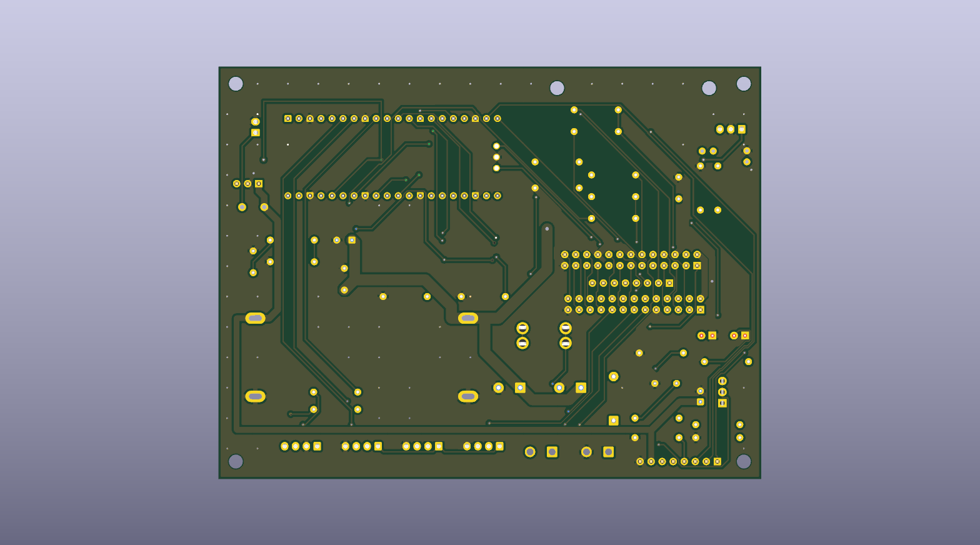
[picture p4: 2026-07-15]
boards/helm/fab/renders/board-bottom.png

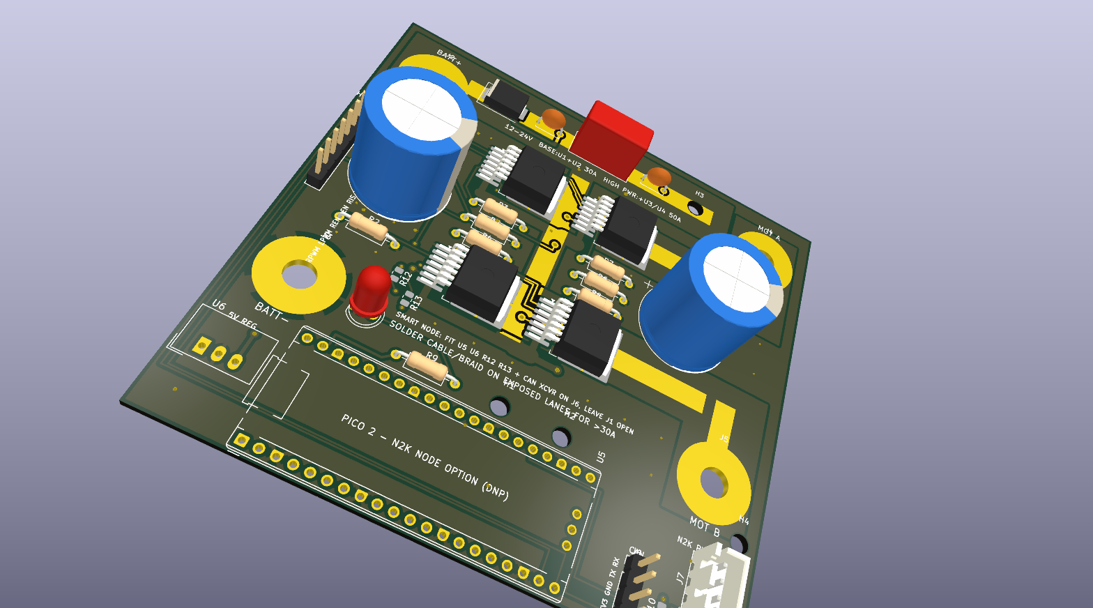
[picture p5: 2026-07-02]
boards/thrust-driver/fab/renders/board-3d.png

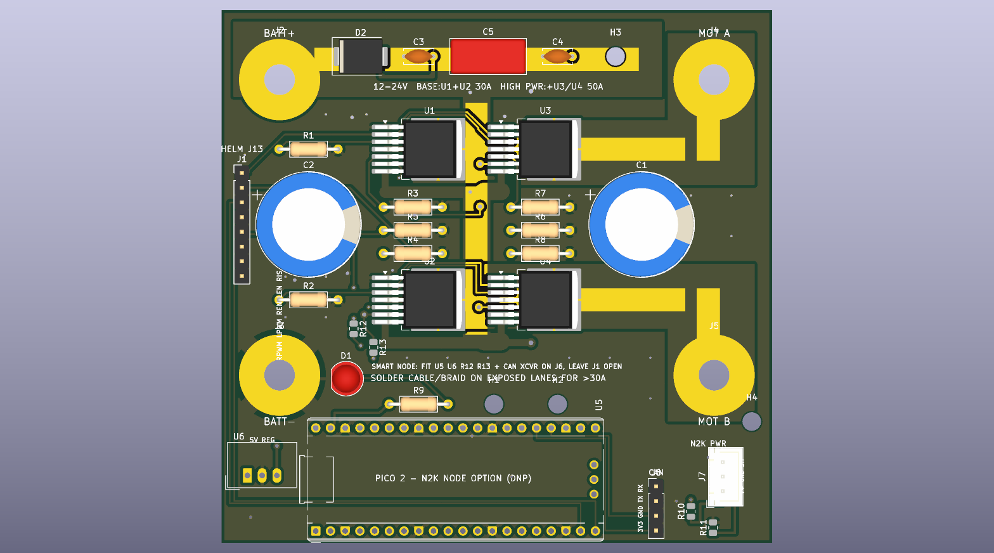
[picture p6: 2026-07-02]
boards/thrust-driver/fab/renders/board-top.png

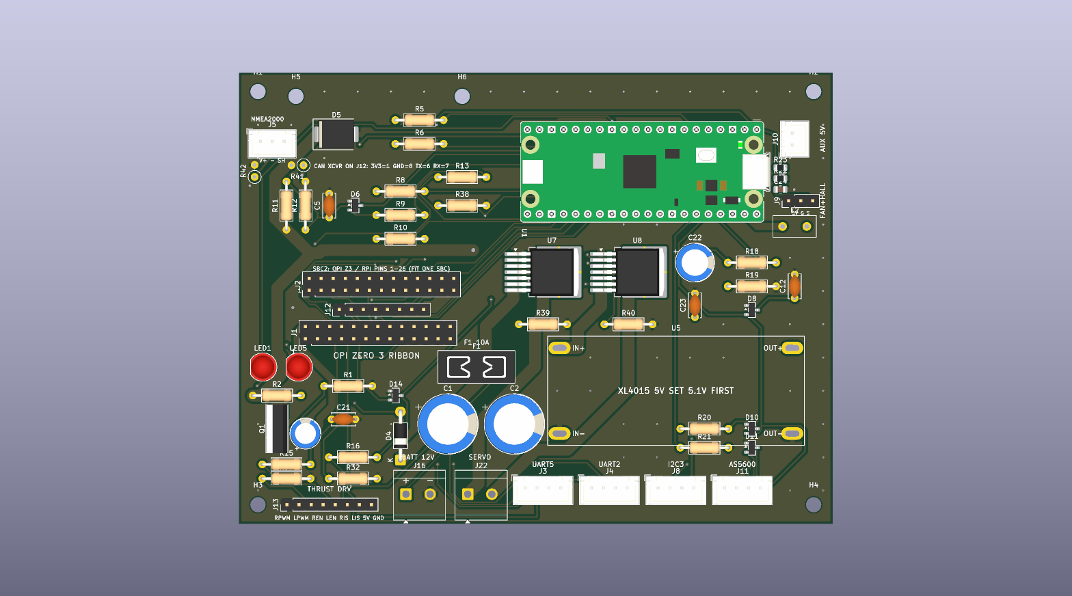
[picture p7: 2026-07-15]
boards/helm/fab/renders/board-top.png

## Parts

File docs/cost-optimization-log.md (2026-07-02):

# Cost-optimization log — 10 passes (2026-07-02)

Baseline: v2 board, 200×150 mm 2-layer **2 oz**, ~$97 components + ~$14 PCB
per board (qty-5 PCB order, single-unit part prices).

| # | Pass | Change | Δ per board |
|---|---|---|---|
| 1 | Value consolidation | R39/R40 51k → 47k (merges with R1's 47k; BTN8982 slew-rate spec allows 6.8k–51k). Distinct resistor values 14 → 13, one fewer order line. | ≈ $0 (order simplicity) |
| 2 | Indicator trim | 5 LEDs → 2. Kept: VIN power (LED1), Pico status (LED5). Dropped: +5V, +12V rail LEDs, Pi heartbeat (rails are provable with a meter; heartbeat is visible on the touchscreen). Frees Pi GPIO26. | −$0.25, −6 parts |
| 3 | Connector de-population | J2 (40-pin breakout) and J12 (Pico util) → DNP. Footprints stay for debugging; headers cost little but every hand-soldered joint costs build time (80 joints). | −$0.60, −88 joints |
| 4 | 12 V buck DNP | U6 (Pololu D36V50F12, $19.95) → DNP by default. On a 12 V-battery boat (this project), J17 gets a wire link and the battery feeds the 12 V rail directly. U6 is populated only for 24–48 V systems. | **−$19.95** |
| 5 | Protection audit | Q1/D4/D5 reverse-battery + TVS, servo IS conditioning, AS5600 line clamps (D10/D11 + R20/R21): all reviewed, all kept — each protects against a plausible marine-wiring fault for well under $1 total. | $0 (documented) |
| 6 | Connector audit | JST-XH ($0.09) and CUI terminal blocks ($0.37) reviewed against cheaper pin headers: kept — locking/screw connections earn their cost on a vibrating boat. Blade-fuse holder kept over 5×20 clips for the same reason. | $0 (documented) |
| 7 | Cost-driver analysis | Itemized the BOM: the on-board thrust bridge (8 FETs $27.60 + driver/sensor/bulk-caps ~$9) plus its consequences (2 oz copper ≈ +$6/board, ~40 % of board area, heatsink bar) accounted for **≈ $45/board**. Flagged for architectural review → pass 10. | (analysis) |
| 8 | Production path (doc) | For 100+ volume: migrate passives/diodes to SMD, replace Pico module with RP2350 + flash, panelize. Documented in this log; not applied to the hand-build design. | (future) |
| 9 | Voltage-variant BOM | 12 V-only builds may substitute 25 V-rated electrolytics for C1/C2 (470 µF): EEU-FR1E471 ≈ half the price of the 63 V part. Default BOM stays 63 V so the same board can go on 24–48 V systems. | −$0.60 (12 V variant) |
| 10 | **External thrust driver** | Removed the entire on-board H-bridge (8× IRF100P219, HIP4082, ACS758, bootstrap parts, 2200 µF bulk caps, TVS, film cap, M5 lugs — 34 parts). Replaced with **J13**, an 8-pin header with the standard IBT-2/BTS7960 pinout (RPWM, LPWM, R_EN, L_EN, R_IS, L_IS, 5 V, GND) driving the user's existing external driver. IS outputs are mixed and clamped into the Pico ADC, EN lines pull down so the driver stays dead when the Pico is absent. Board: 200×150 2 oz → **150×120 1 oz**. | **−$41 parts, −$8 PCB** |

## Result

| | v2 (on-board bridge) | v3 (after 10 passes) |
|---|---|---|
| Components (12 V build) | ~$97 | **~$35** |
| PCB (qty 5, per board) | ~$14 (2 oz, 200×150) | **~$6 (1 oz, 150×120)** |
| Hand-solder joints | ~480 | ~300 |
| Board size | 200×150 mm | 150×120 mm |
| Heatsink / 2 oz / lugs | required | none |
| **Per assembled board** | **~$111** | **~$41** |

External driver (already owned) carries all battery/motor current; the helm
board is now logic + servo only. Wiring: driver's 8-pin harness → J13
(pin 1 = RPWM, matches the silkscreen), battery 12 V → J16, servo motor →
J22, AS5600 cable → J11.

Firmware deltas (vanchor-ng): thrust moves from the HIP4082 pin set back to
the classic RPWM/LPWM/R_EN/L_EN interface on **GP12/GP13/GP14/GP15**
(THR_RPWM/THR_LPWM/THR_R_EN/THR_L_EN); THR_IS stays on GP27 (now the
external driver's IS mix); GP16 and GP26 are freed.

## v3.1 addendum — 12V-only commit (user decision, 2026-07-02)

With the thrust bridge external, the 48V input requirement died with it.
Board committed to 12V (car battery, 14.4V charging):

- **U5 (Pololu D36V50F5, $19.95) removed** → J14 header (VIN GND 5V GND) for
  a generic XL4015/LM2596-class buck module (~$2.50), strapped to the board
  via two M3 holes beside it. Set to 5.1V before fitting.
- **U6 + J17 removed entirely** — the servo bridge (BTN8982, 5.5-40V) runs
  straight off protected VIN.
- D5 TVS: SMCJ58A → **SMCJ18A** (proper 12V clamping); C1/C2 → 25V-rated;
  R2 LED resistor 15k/0.5W → 2.2k; VBAT divider rescaled 47k/10k
  (reuses existing values, kills the 6.8k and 100k-divider line items).

| | v3 | v3.1 |
|---|---|---|
| Components | ~$35 | **~$15 + $2.50 buck module ≈ $18** |
| Line items | 44 | 40 |
| Input range | 12-48V | 12V only (14.4V charging) |

## v4 addendum — Orange Pi Zero 3 + board shrink (user decision, 2026-07-02)

- Raspberry Pi 4/5 (40-pin, under-board) → **Orange Pi Zero 3** on a 2×13
  socket, module on top, powered through the header (no USB-C). SBC cost:
  Pi 4 ($45-60) → Zero 3 ($18-25).
- Board **150×120 → 125×95 mm** (−34 %): low parts live under the module,
  JSTs consolidated (Zero 3 exposes 2 UARTs, not 5 → J5/J6/J7 dropped).
- PCB ≈ $15-18 / 5 pcs. Parts unchanged ≈ $18 → **≈ $22/board assembled**,
  ≈ $45 with the Zero 3 itself.

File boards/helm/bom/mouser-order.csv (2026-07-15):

Mfr Part Number | Quantity | Description
EEU-FR1E471B | 2 | C1 C2 470uF 25V radial
EEU-FR1E101 | 1 | C3 100uF radial
EEU-FR1E221 | 1 | C22 220uF 25V radial
K104K15X7RF5TL2 | 5 | C5 C12 C21 C23 100nF disc (+1 spare)
BZX85C12-TAP | 2 | D4 12V zener (+1)
SMCJ18A | 2 | D5 TVS 18V (+1)
BAT54SLT1G | 6 | D6 D8 D10 D11 D14 dual schottky (onsemi; +1)
3568 | 1 | F1 mini blade fuse holder (Keystone; if no match search DigiKey or use any PCB mini-blade holder)
0297010.WXNV | 2 | F1 10A mini blade fuse (+1)
MF-R250 | 1 | F2 polyfuse 2.5A
61302621121 | 1 | J1 2x13 male header
B4B-XH-A(LF)(SN) | 4 | J3 J4 J8 J11 JST-XH 4p
B2B-XH-A(LF)(SN) | 1 | J10 JST-XH 2p
XHP-4 | 4 | JST housings 4p
XHP-2 | 1 | JST housing 2p
SXH-001T-P0.6 | 25 | JST crimps
TB007-508-02 | 2 | J16 J22 terminal blocks
61300211121 | 1 | J9 1x2 header
61300811121 | 1 | J13 1x8 header
61300411121 | 1 | J14 1x4 header
WP7113GD | 1 | LED1 green 5mm
WP7113YD | 1 | LED5 yellow 5mm
IRF9540NPBF | 1 | Q1 P-FET
CFR-25JB-52-47K | 5 | 47k (+1)
CFR-25JB-52-2K2 | 2 | 2.2k (+1)
CF1/4CT52R102J | 6 | R8 R13 R15 R16 R19 1k KOA carbon film (+1; alt: Yageo MFR-25FBF52-1K metal film)
CFR-25JB-52-4K7 | 3 | 4.7k (+1)
CFR-25JB-52-10K | 3 | 10k (+1)
CFR-25JB-52-100R | 3 | 100R (+1)
CFR-25JB-52-100K | 3 | 100k (+1)
CFR-25JB-52-20K | 2 | 20k (+1)
SC1632 | 1 | U1 Pico 2 (if OOS: Electrokit 41022-ish stocks it)
BTN8982TAAUMA1 | 2 | U7 U8 servo bridges (full Infineon ordering code for BTN8982TA)
71600-026LF | 2 | 26p IDC ribbon sockets (make the Zero 3 cable)
3365/26-100SF | 1 | 26-way ribbon cable 3M (1 unit = enough)
# R41/R42 (NMEA2000 0R DNP options): THT vertical axials - fit a wire link or any 1/4W 0R if used
# 5V buck NOT in this cart: add an XL4015 5A module (~25kr) to the AliExpress order
# alongside the Zero 3. All-Mouser fallback if preferred: CUI P7805-2000-S (2A SIP-3
# ~$8) - enough for Zero3+fan but then power the screen separately.

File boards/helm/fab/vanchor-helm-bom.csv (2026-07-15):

Ref | Value | Footprint | MPN | Qty | DNP
C1,C2 | 470u/25V | Capacitor_THT:CP_Radial_D12.5mm_P5.00mm | EEU-FR1E471B | 2
C3 | 100u | Capacitor_THT:CP_Radial_D6.3mm_P2.50mm | EEU-FR1E101 | 1
C5,C12,C21,C23 | 100n | Capacitor_THT:C_Disc_D5.0mm_W2.5mm_P5.00mm |  | 4
C22 | 220u/25V | Capacitor_THT:CP_Radial_D8.0mm_P3.50mm | EEU-FR1E221 (220uF/25V) | 1
C24 | 100n | Capacitor_SMD:C_0805_2012Metric |  | 1
D4 | BZX85C12 | Diode_THT:D_DO-41_SOD81_P10.16mm_Horizontal | BZX85C12-TAP | 1
D5 | SMCJ18A | Diode_SMD:D_SMC | SMCJ18A | 1
D6,D8,D10,D11,D14 | BAT54S | Package_TO_SOT_SMD:SOT-23 | BAT54S,215 | 5
F1 | 10A blade | Fuse:Fuseholder_Blade_Mini_Keystone_3568 | 3568 | 1
F2 | MF-R250 2.5A | vanchor-helm:MF-R250_Straight | MF-R250 | 1
J1 | OPI_Z3_26PIN | Connector_PinHeader_2.54mm:PinHeader_2x13_P2.54mm_Vertical | 61302621121 (Wurth 2x13 2.54mm male header) | 1
J2 | SBC2_OPI_RPI26 | Connector_PinHeader_2.54mm:PinHeader_2x13_P2.54mm_Vertical |  | 1 | DNP
J3 | UART5 ttyAS5 | Connector_JST:JST_XH_B4B-XH-A_1x04_P2.50mm_Vertical | JST B4B-XH-A(LF)(SN) | 1
J4 | UART2 ttyAS2 | Connector_JST:JST_XH_B4B-XH-A_1x04_P2.50mm_Vertical | JST B4B-XH-A(LF)(SN) | 1
J5 | NMEA2000 PWR | Connector_JST:JST_XH_B3B-XH-A_1x03_P2.50mm_Vertical | JST B4B-XH-A(LF)(SN) | 1
J8 | I2C3 spare | Connector_JST:JST_XH_B4B-XH-A_1x04_P2.50mm_Vertical | JST B4B-XH-A(LF)(SN) | 1
J9 | FAN + HALL | Connector_PinHeader_2.54mm:PinHeader_1x03_P2.54mm_Vertical |  | 1
J10 | AUX 5V (screen) | Connector_JST:JST_XH_B2B-XH-A_1x02_P2.50mm_Vertical | JST B2B-XH-A(LF)(SN) | 1
J11 | AS5600 | Connector_JST:JST_XH_B4B-XH-A_1x04_P2.50mm_Vertical | JST B4B-XH-A(LF)(SN) | 1
J12 | PICO UTIL | Connector_PinHeader_2.54mm:PinHeader_1x08_P2.54mm_Vertical |  | 1 | DNP
J13 | THRUST DRV | Connector_PinHeader_2.54mm:PinHeader_1x08_P2.54mm_Vertical |  | 1
J16 | BATT 12V | TerminalBlock_CUI:TerminalBlock_CUI_TB007-508-02_1x02_P5.08mm_Horizontal |  | 1
J22 | SERVO MOTOR | TerminalBlock_CUI:TerminalBlock_CUI_TB007-508-02_1x02_P5.08mm_Horizontal | CUI TB007-508-02 | 1
LED1 | green | LED_THT:LED_D5.0mm |  | 1
LED5 | yellow | LED_THT:LED_D5.0mm |  | 1
Q1 | IRF9540N | Package_TO_SOT_THT:TO-220-3_Vertical | IRF9540NPBF | 1
R1,R11,R39,R40 | 47k | Resistor_THT:R_Axial_DIN0207_L6.3mm_D2.5mm_P10.16mm_Horizontal |  | 4
R2,R5,R6 | 2.2k | Resistor_THT:R_Axial_DIN0207_L6.3mm_D2.5mm_P10.16mm_Horizontal |  | 3 | DNP
R8,R13,R15,R16,R19 | 1k | Resistor_THT:R_Axial_DIN0207_L6.3mm_D2.5mm_P10.16mm_Horizontal |  | 5
R9,R10 | 4.7k | Resistor_THT:R_Axial_DIN0207_L6.3mm_D2.5mm_P10.16mm_Horizontal |  | 2
R12,R18 | 10k | Resistor_THT:R_Axial_DIN0207_L6.3mm_D2.5mm_P10.16mm_Horizontal |  | 2
R20,R21 | 100R | Resistor_THT:R_Axial_DIN0207_L6.3mm_D2.5mm_P10.16mm_Horizontal |  | 2
R22 | 10k | Resistor_SMD:R_0805_2012Metric |  | 1
R23 | 1k | Resistor_SMD:R_0805_2012Metric |  | 1
R30,R32 | 100k | Resistor_THT:R_Axial_DIN0207_L6.3mm_D2.5mm_P10.16mm_Horizontal |  | 2
R38 | 20k | Resistor_THT:R_Axial_DIN0207_L6.3mm_D2.5mm_P10.16mm_Horizontal |  | 1
R41,R42 | 0R DNP | Resistor_THT:R_Axial_DIN0207_L6.3mm_D2.5mm_P2.54mm_Vertical |  | 2 | DNP
U1 | Pico 2 | vanchor-helm:RaspberryPi_Pico_TH_SWD | Raspberry Pi Pico 2 (SC1632) | 1
U5 | XL4015 5A | vanchor-helm:XL4015_Module | XL4015 5A module (AliExpress) | 1
U7,U8 | BTN8982TA | Package_TO_SOT_SMD:TO-263-7_TabPin4 | BTN8982TA | 2

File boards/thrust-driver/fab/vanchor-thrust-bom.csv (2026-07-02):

Ref | Value | Footprint | MPN | Qty | DNP
C1,C2 | 2200u/35V | Capacitor_THT:CP_Radial_D18.0mm_P7.50mm |  | 2
C3,C4 | 100n | Capacitor_THT:C_Disc_D5.0mm_W2.5mm_P5.00mm |  | 2
C5 | 1u/100V film | Capacitor_THT:C_Rect_L13.0mm_W6.0mm_P10.00mm_FKS3_FKP3_MKS4 |  | 1
D1 | green | LED_THT:LED_D5.0mm |  | 1
D2 | SMCJ33A | Diode_SMD:D_SMC |  | 1
J1 | HELM J13 1:1 | Connector_PinHeader_2.54mm:PinHeader_1x08_P2.54mm_Vertical |  | 1
J2 | LUG BATT+ | vanchor-helm:Lug_M5 |  | 1
J3 | LUG BATT- | vanchor-helm:Lug_M5 |  | 1
J4 | LUG MOT A | vanchor-helm:Lug_M5 |  | 1
J5 | LUG MOT B | vanchor-helm:Lug_M5 |  | 1
J6 | CAN XCVR 3V3 | Connector_PinHeader_2.54mm:PinHeader_1x04_P2.54mm_Vertical |  | 1
J7 | NMEA2000 PWR | Connector_JST:JST_XH_B3B-XH-A_1x03_P2.50mm_Vertical |  | 1
R1,R2 | 100k | Resistor_THT:R_Axial_DIN0207_L6.3mm_D2.5mm_P10.16mm_Horizontal |  | 2
R3,R4,R7,R8 | 51k | Resistor_THT:R_Axial_DIN0207_L6.3mm_D2.5mm_P10.16mm_Horizontal |  | 4 | DNP
R5,R6,R9 | 1k | Resistor_THT:R_Axial_DIN0207_L6.3mm_D2.5mm_P10.16mm_Horizontal |  | 3
R10,R11 | 0R DNP | Resistor_SMD:R_0805_2012Metric |  | 2 | DNP
R12,R13 | 1k DNP | Resistor_SMD:R_0805_2012Metric |  | 2 | DNP
U1-U4 | BTN8982TA | Package_TO_SOT_SMD:TO-263-7_TabPin4 |  | 4 | DNP
U5 | Pico 2 (DNP) | vanchor-helm:RaspberryPi_Pico_TH_SWD |  | 1 | DNP
U6 | R-78E5.0-0.5 (DNP) | Converter_DCDC:Converter_DCDC_TRACO_TSR-1_THT |  | 1 | DNP

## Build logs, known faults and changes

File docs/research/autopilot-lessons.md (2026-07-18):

# Lessons from ArduPilot and pypilot (firmware + electronics)

Researched 2026-07-19 against our helm-pico firmware and both boards.
pypilot is the closest cousin (Raspberry Pi autopilot + Arduino motor
controller over serial, marine, same problem shape as vanchor); ArduPilot
is the reliability benchmark. Below: what they do, what we already match,
and a prioritized punch list of what's worth stealing.

## 1. pypilot — firmware lessons

**Protocol & link.** Binary 4-byte frames with CRC-8 at 38400; the
firmware *waits for several consecutive valid frames before recognizing
commands at all* (noise can't twitch the motor at plug-in), and a **250 ms
serial timeout disengages** (vs our 800 ms contract watchdog). Our CRC
gate + enables-low-until-first-valid-command is the same idea; their
sync-window is stricter.

**Fault model — the biggest gap for us.** The controller continuously
reports FLAGS with a rich vocabulary:

- `OVERCURRENT_FAULT`, and **directional** `PORT/STARBOARD_OVERCURRENT` —
  a stall inhibits *further motion in that direction only*; the way back
  is always allowed. Our stall detection stops the whole servo drive.
- `DRIVER_TIMEOUT` — commanded, but **no current observed**: catches a
  broken motor wire / dead bridge, the failure our loop can't currently
  see (we'd just report a steering stall eventually).
- `SATURATED` — commanded faster than the drive can move ("a faster motor
  would improve steering"): performance telemetry, not a fault.
- Overvoltage, controller-overtemp, motor-overtemp (10 k NTC, 60–70 °C
  typical), fuse-corruption (`BAD_FUSES`) flags.

**Stall-vs-feedback philosophy.** Rudder feedback is *optional* and can
fail underway; current-based stall detection is the primary protection and
`max_current` is "the critical first tuning parameter" (4–7 A tiller,
15–20 A hydraulic). Validates our choice to keep `steer.stall_a` runtime-
tunable — but theirs defaults ON, ours defaults OFF.

**Motion shaping.** Separate slew rates (`servo.slew_speed` /
`servo.slew_slow`), a **minimum motor speed** ("short fast corrections"
beat inefficient slow crawling), a **minimum dwell between commands**
(`servo.period` ~0.3–0.4 s, anti-chatter), and a hard field lesson:
rudder speed is "one of the most important considerations" — ±30° in
6–8 s minimum, 15–20 °/s is good.

**Persistence.** EEPROM values are written in **three redundant banks**
and cross-checked on read — corruption loses nothing. They also insist on
enabling the **brown-out detector** because undervoltage during writes
corrupts AVR flash. Our single image + CRC32 falls back to *defaults* on
corruption: safe but lossy.

**Power stage.** Adaptive PWM — 62.5 Hz at full power, ~16 kHz partial —
same loss-vs-noise logic as our current-adaptive schedule (independent
validation). Bootstrap-refresh cycling at low duty. Clutch output with
full-power pull-in then PWM hold; `use_brake` (short the windings) is a
*tradeoff*, explicitly bad "if quick manual override is needed". Our worm
gear is always-brake with no clutch: no manual override by design —
that's an operational fact worth stating in the docs.

**ADC craft.** Heavy oversampling per channel, first 3 samples discarded
after mux switch, 32-bit accumulators; *ratiometric mode* makes the pot
feedback supply-independent (our AS5600 is digital — immune anyway).

## 2. ArduPilot — firmware lessons

**Watchdog culture.** Independent hardware watchdog + on-reset forensics:
a `WDG` log message, a `crash_dump.bin` of CPU state, and since 4.5.1 an
un-armable vehicle until the operator acknowledges the crash dump. The
lesson isn't the watchdog (we have one) — it's that **a watchdog reset is
a loud, sticky event**, never a silent reboot. RP2350 gives us
`watchdog_caused_reboot()` + scratch registers for free.

**Pre-arm check culture.** A comprehensive, categorized checklist gates
arming (sensor health, param storage readable, battery, calibration...),
with a bitmask escape hatch that exists but is discouraged — same
philosophy as our `VANCHOR_REQUIRE_CRC=0` bench switch. We have a minimal
version (enables low until first command; never drive blind on bad
feedback); we don't yet *verify* config storage or sensors as an explicit
gate with a reportable reason.

**Parameters.** AP_Param: save-only-if-changed (we match), backward-
compatible layout growth (we match with append-only), validation, and
flush-pending-saves-before-reboot. Their storage sits behind a layered
abstraction (HAL → StorageManager regions) — overkill at our scale, but
the *regions* idea (params / waypoints / signing keys separated) is why
they survived 15 years of format evolution.

**Failsafes are layered and graduated.** Two-stage battery failsafe
(warn → act), RC-loss vs GCS-loss vs EKF-loss handled distinctly, each
with an explicit configured action. Maps to us as: firmware reports
(VBAT, flags), the Pi decides policy — keep firmware policy-free.

**Observability.** Everything is logged (dataflash) and replayable; bugs
get found because the data exists. Our equivalent is free: the Pi should
log the raw `A`/`E`/`C`/`I` line streams (vanchor-ng side, one config
knob in their logging).

## 3. Electronics lessons (both projects)

| Practice | Them | Us today | Gap |
|---|---|---|---|
| Reverse polarity + fuse at entry | pypilot 10 A fuse + protection | F1 + P-FET ideal diode | none |
| Brown-out detection | AVR BOD fuse mandatory | RP2350 built-in BOR | none |
| V/I telemetry at the controller | both | VBAT + 2× IS ADCs | none |
| Power-stage temperature sensing | 10 k NTC, 60–70 °C limits | **none** (BTN8982's internal OT trip only — silent) | NTC pad on driver rev 2 / smart-node ADC |
| Endstop switch inputs | port/stbd pull-low fault pins | soft endstops only (`steer.range`) | GP2/GP3 on J12 could take switches |
| Logic/power isolation | optical isolation on serial | shared-ground ribbon/USB | acceptable (same enclosure); isolate only if CAN/0183 ground loops bite |
| EMI: motor wires vs sensors | twist pairs, ≥10 cm from IMU, compass ≥1 m from ferrous | HWT901B ≥30 cm note | add "twist J22/J13/battery pairs" to assembly docs |
| Feedback sensor wear | hall/AS5600 over pots | AS5600 | none — we're on their end state |

## 4. Recommendations (prioritized)

1. **A/B config sectors (power-loss-proof persistence)** — pypilot's
   triple-bank redundancy, adapted to NOR flash: alternate saves between
   TWO 4 kB sectors with a monotonic sequence number; boot loads the
   newest valid image. Never erases the only good copy (fixes our
   documented "power cut during erase → defaults" hole) and doubles wear
   life. Small change to `confPersist`/`confDeserialize`.
2. **Fault-flags telemetry + directional stall inhibit** — adopt the
   pypilot fault vocabulary: a flags word (stall-port, stall-stbd,
   overcurrent, driver-timeout = commanded-but-no-current, saturated,
   low-vbat, wdg-reboot) reported in `INFO` and a compact periodic `S
   <flags>*HH` line; make servo stall inhibit only the stalled direction.
   Firmware-only; the Pi can ignore it until it wants it.
3. **Watchdog forensics** — on boot read `watchdog_caused_reboot()`,
   count reboots in a watchdog scratch register, report cause + count in
   `INFO` (`I reset wdg n=2`), set the wdg flag bit until an operator
   `CONF`/command clears it. Loud, sticky, cheap.
4. **Motion-shaping config** — split `thr.slew` into up/down (fast to cut
   power, slow to apply — pypilot slew pair), add optional
   `steer.min_pwm_time`-style dwell (their `servo.period` anti-chatter)
   and consider defaulting `steer.stall_a` ON once calibrated (their
   "critical first parameter").
5. **Pi-side logging note** (vanchor-ng backlog): log raw protocol lines;
   it's the ArduPilot dataflash lesson at zero firmware cost.
6. **Board backlog (rev 2 / smart node)**: NTC footprint near the BTN8982
   pair on the driver (smart-node Pico has spare ADCs); label GP2/GP3 as
   optional endstop inputs; assembly-doc EMI notes (twisted pairs, route
   motor cables away from the HWT901B).

## Sources

- pypilot motor firmware: https://github.com/pypilot/pypilot/blob/master/arduino/motor/motor.ino
- pypilot motor README (BOD/fuses): https://github.com/pypilot/pypilot/blob/master/arduino/motor/README
- pypilot user manual (servo settings, flags, install/EMI): https://pypilot.org/doc/pypilot_user_manual/
- pypilot h-bridge controller: https://pypilot.org/schematics/hbridge_datasheet.htm
- ArduPilot independent watchdog + crash dump: https://ardupilot.org/copter/docs/common-watchdog.html
- ArduPilot pre-arm checks: https://ardupilot.org/copter/docs/common-prearm-safety-checks.html
- ArduPilot storage/EEPROM design: https://ardupilot.org/dev/docs/learning-ardupilot-storage-and-eeprom-management.html
- ArduPilot plane failsafe (layered battery): https://ardupilot.org/plane/docs/apms-failsafe-function.html

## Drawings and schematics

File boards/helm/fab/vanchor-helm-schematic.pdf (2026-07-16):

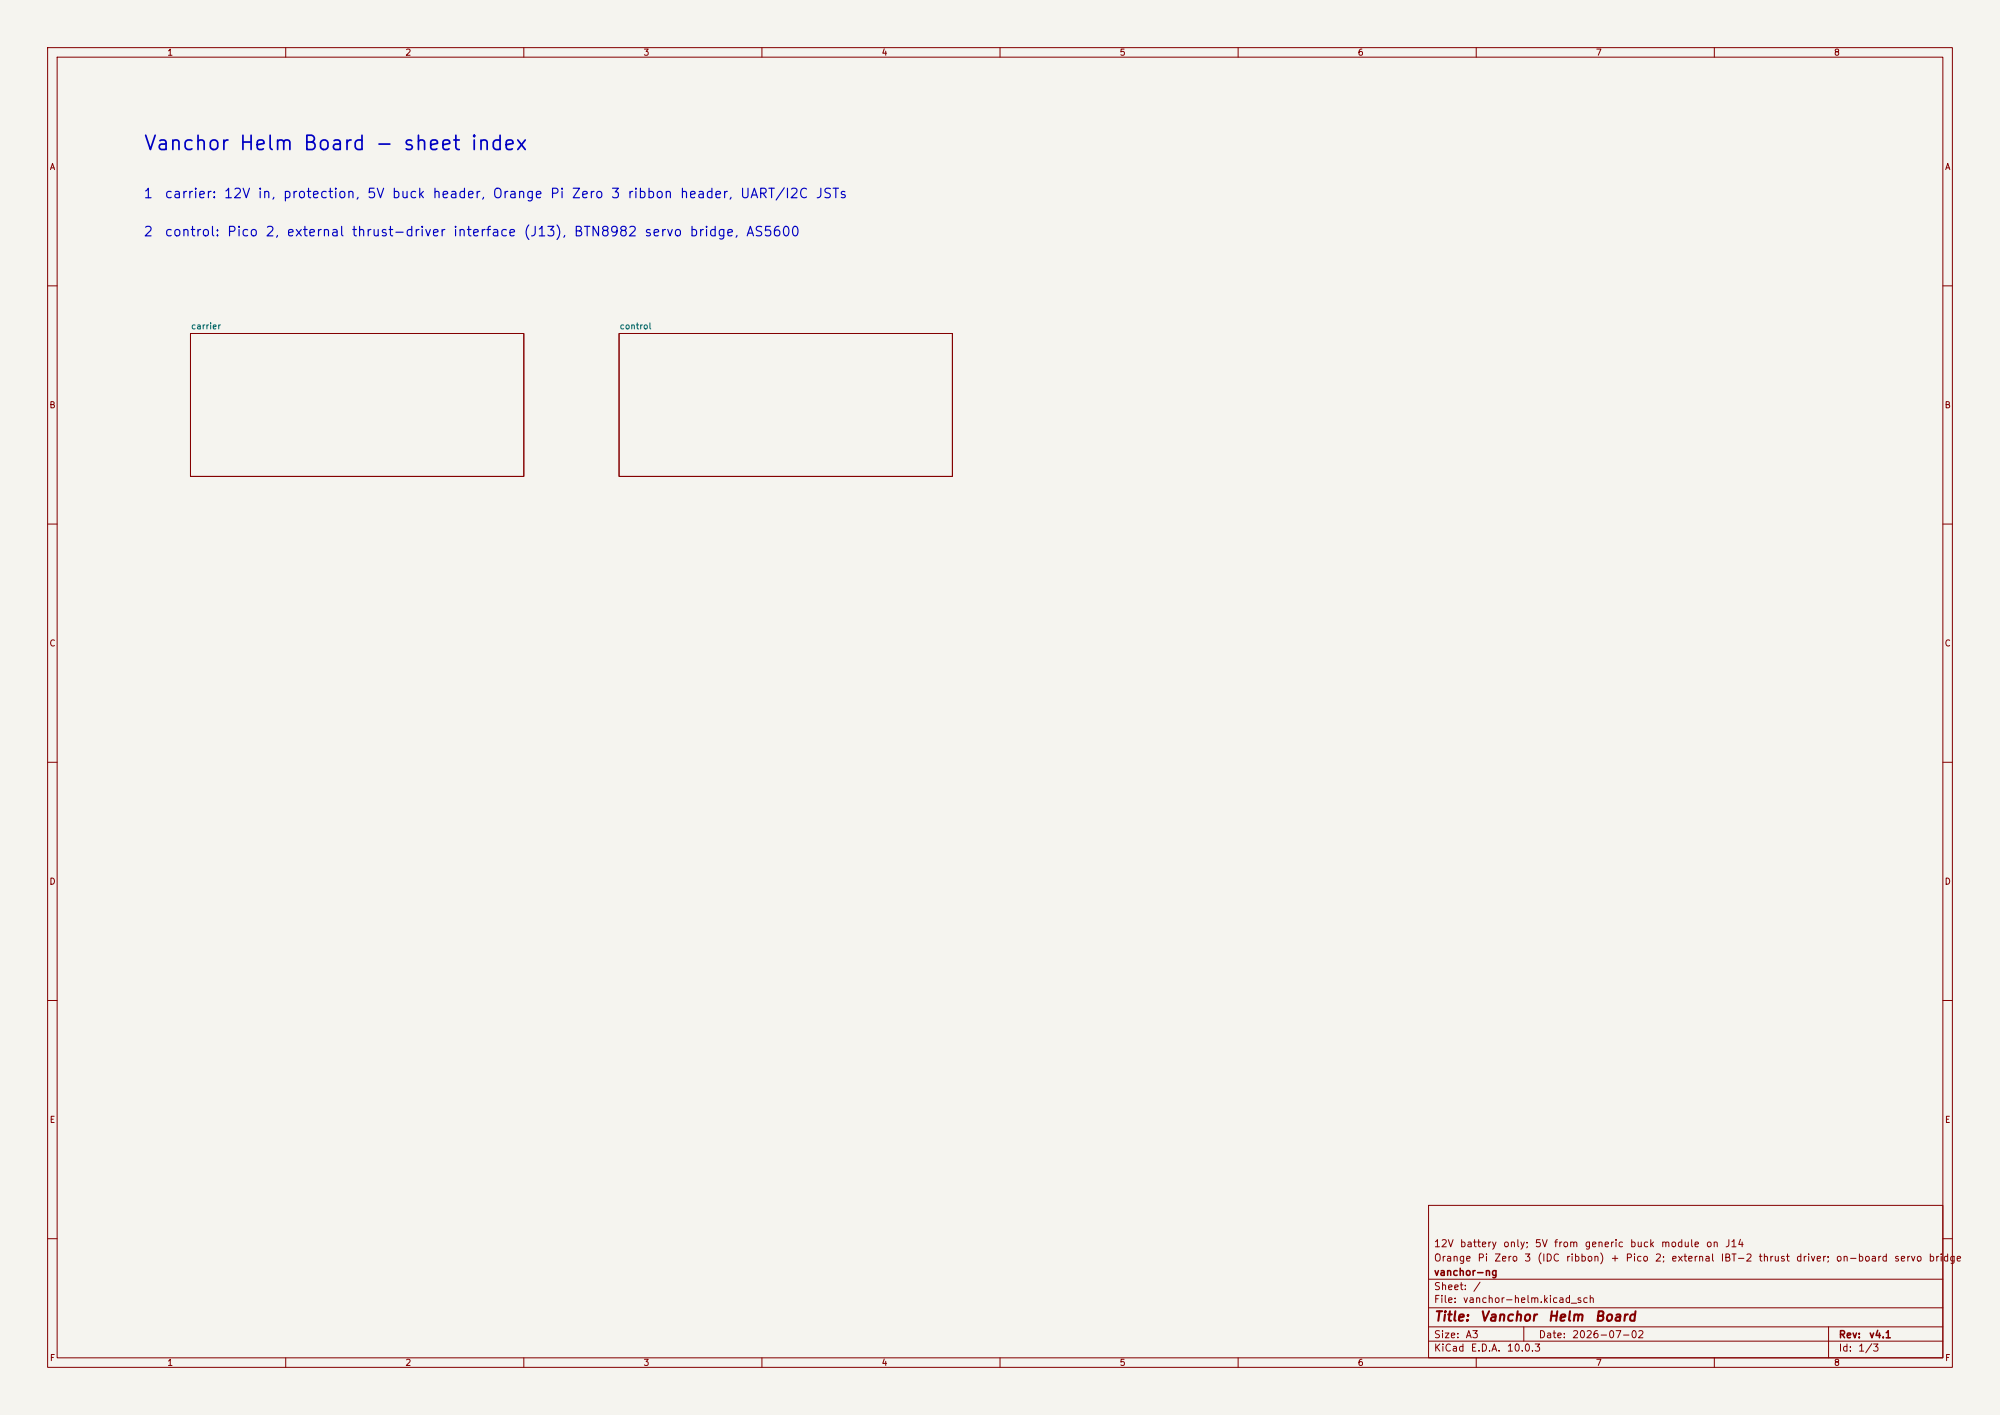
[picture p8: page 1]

1 carrier: 12V in, protection, 5V buck header, Orange Pi Zero 3 ribbon header, UART/I2C JSTs

2 control: Pico 2, external thrust-driver interface (J13), BTN8982 servo bridge, AS5600

12V battery only; 5V from generic buck module on J14
Orange Pi Zero 3 (IDC ribbon) + Pico 2; external IBT-2 thrust driver; on-board servo bridge
vanchor-ng
Sheet: /
File: vanchor-helm.kicad_sch
Title: Vanchor Helm Board

Size: A3 | Rev: v4.1
KiCad E.D.A. 10.0.3 | Id: 1/3 | F Date: 2026-07-02

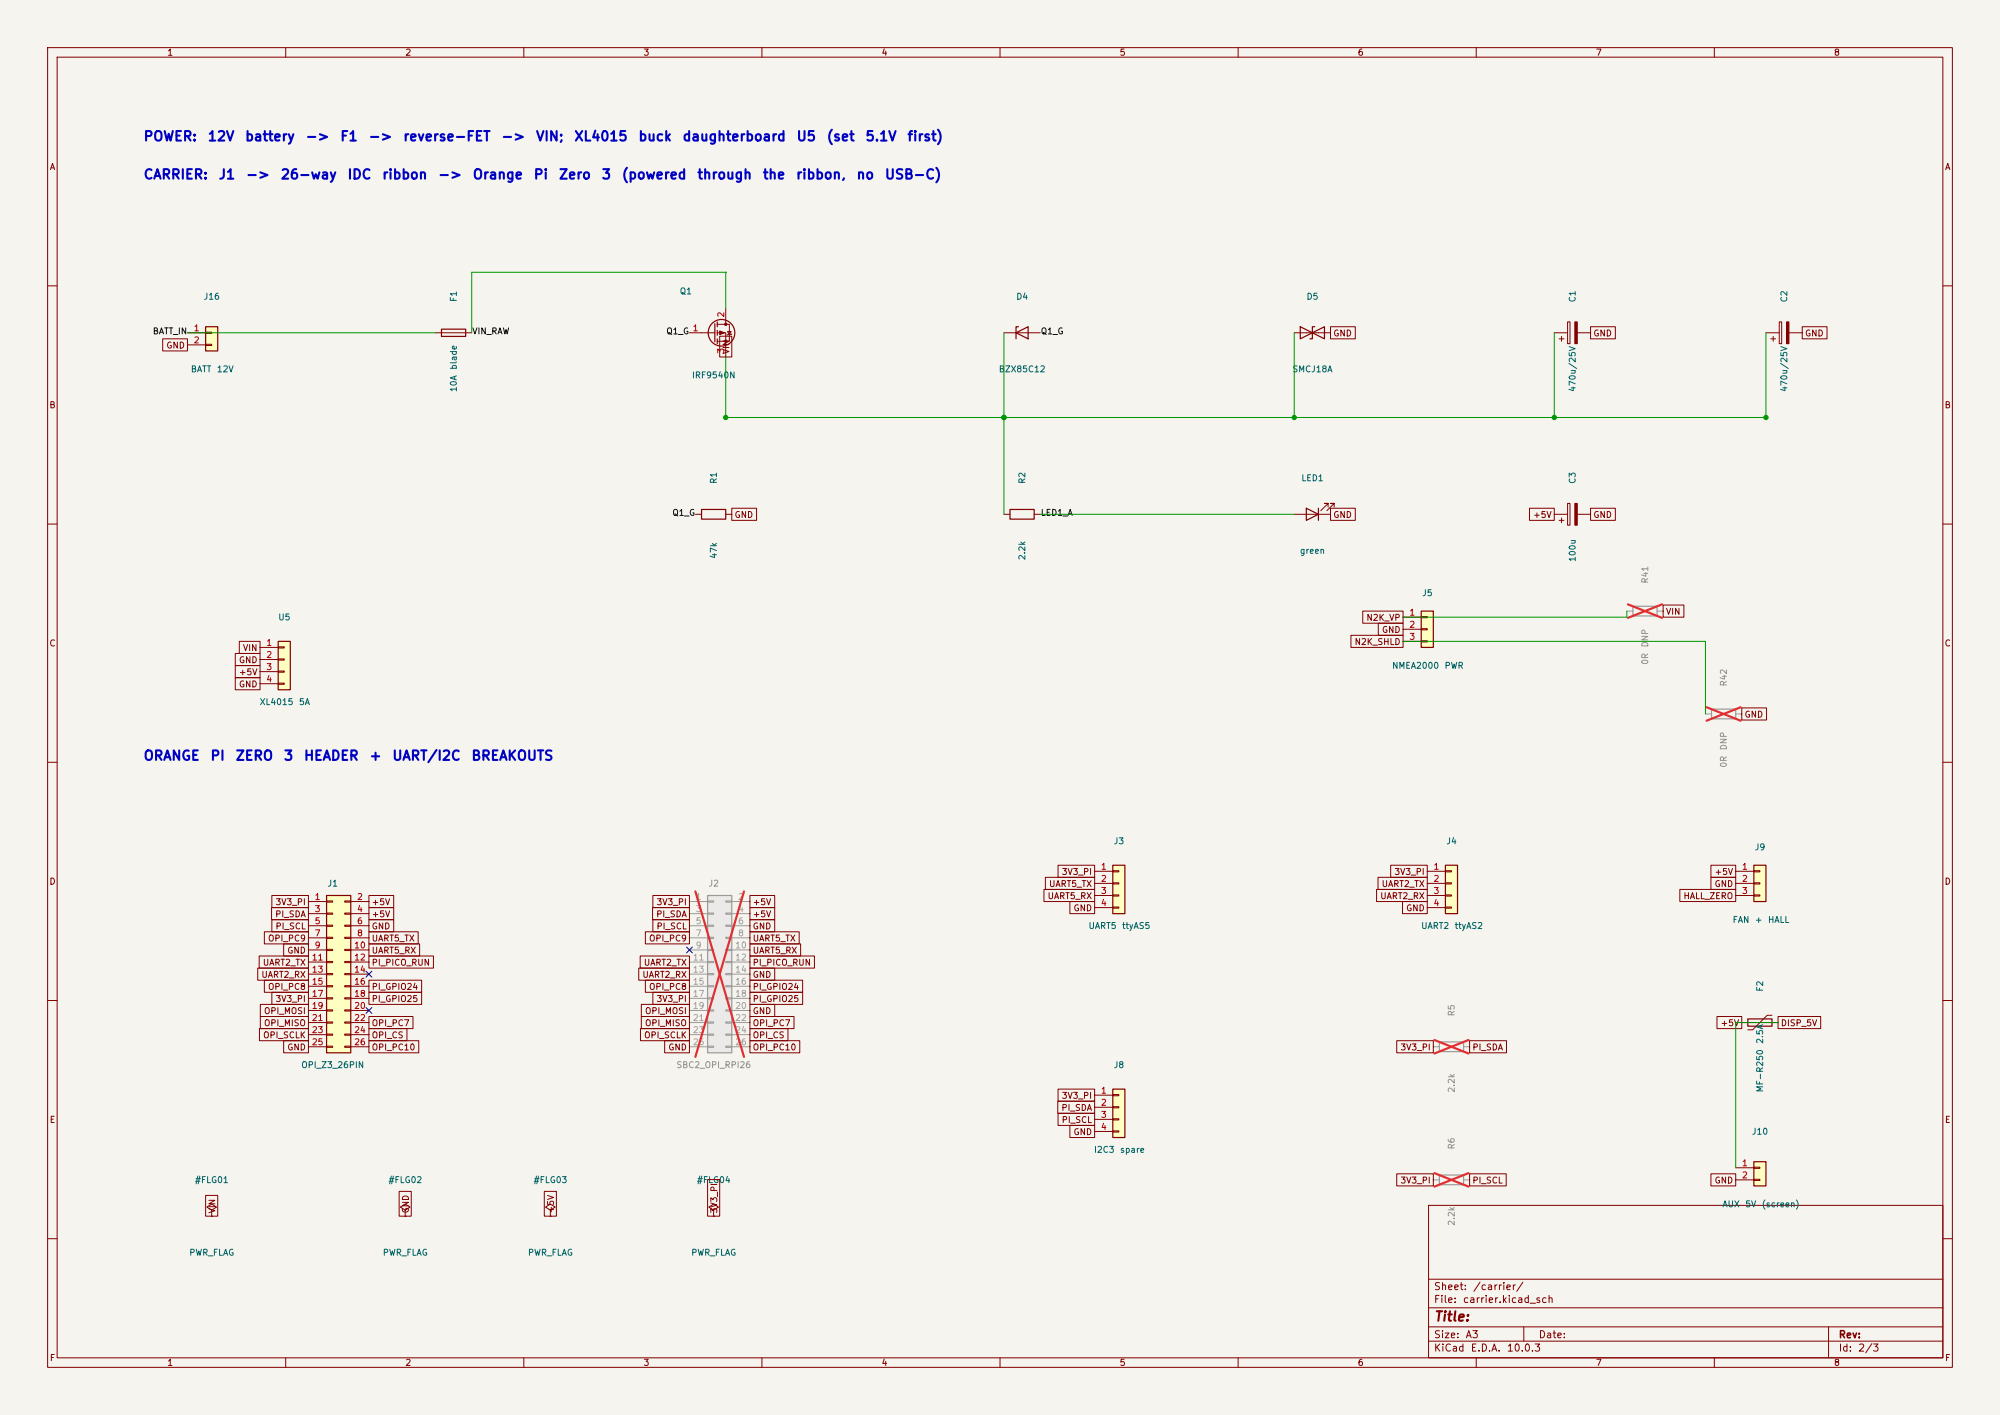
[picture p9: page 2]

POWER: 12V battery -> F1 -> reverse-FET -> VIN; XL4015 buck daughterboard U5 (set 5.1V first)

CARRIER: J1 -> 26-way IDC ribbon -> Orange Pi Zero 3 (powered through the ribbon, no USB-C)

LED1_A ORANGE PI ZERO 3 HEADER + UART/I2C BREAKOUTS

Size: A3 | Rev:

F Date:

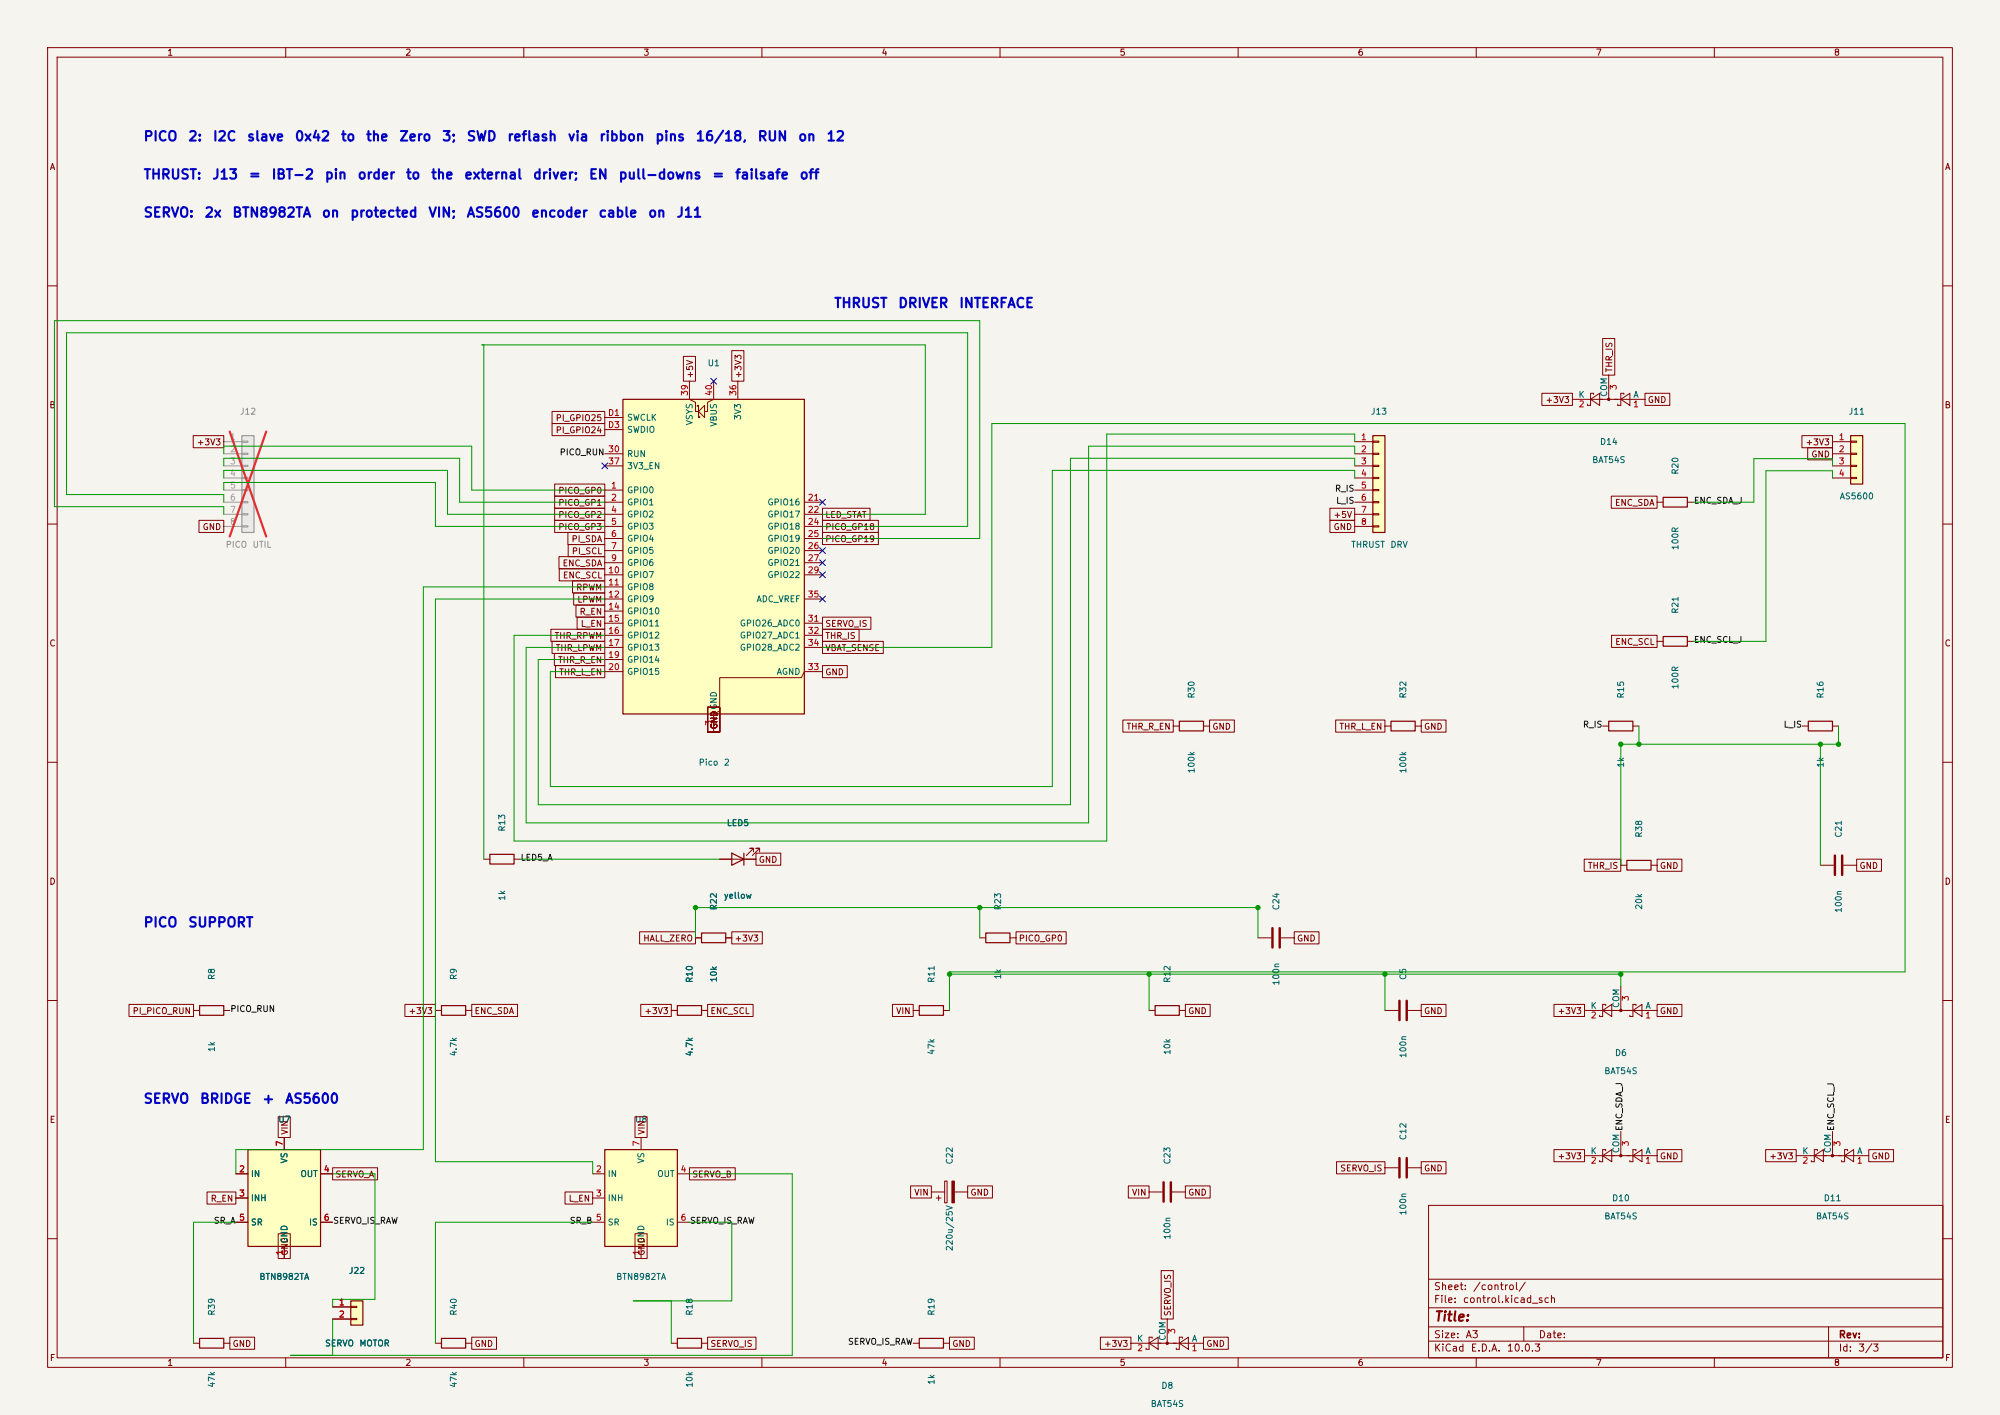
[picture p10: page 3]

PICO 2: I2C slave 0x42 to the Zero 3; SWD reflash via ribbon pins 16/18, RUN on 12
PI_GPIO24 PI_GPIO25 VIN

THRUST: J13 = IBT-2 pin order to the external driver; EN pull-downs = failsafe off

SERVO: 2x BTN8982TA on protected VIN; AS5600 encoder cable on J11

Size: A3 | Rev:

F Date:

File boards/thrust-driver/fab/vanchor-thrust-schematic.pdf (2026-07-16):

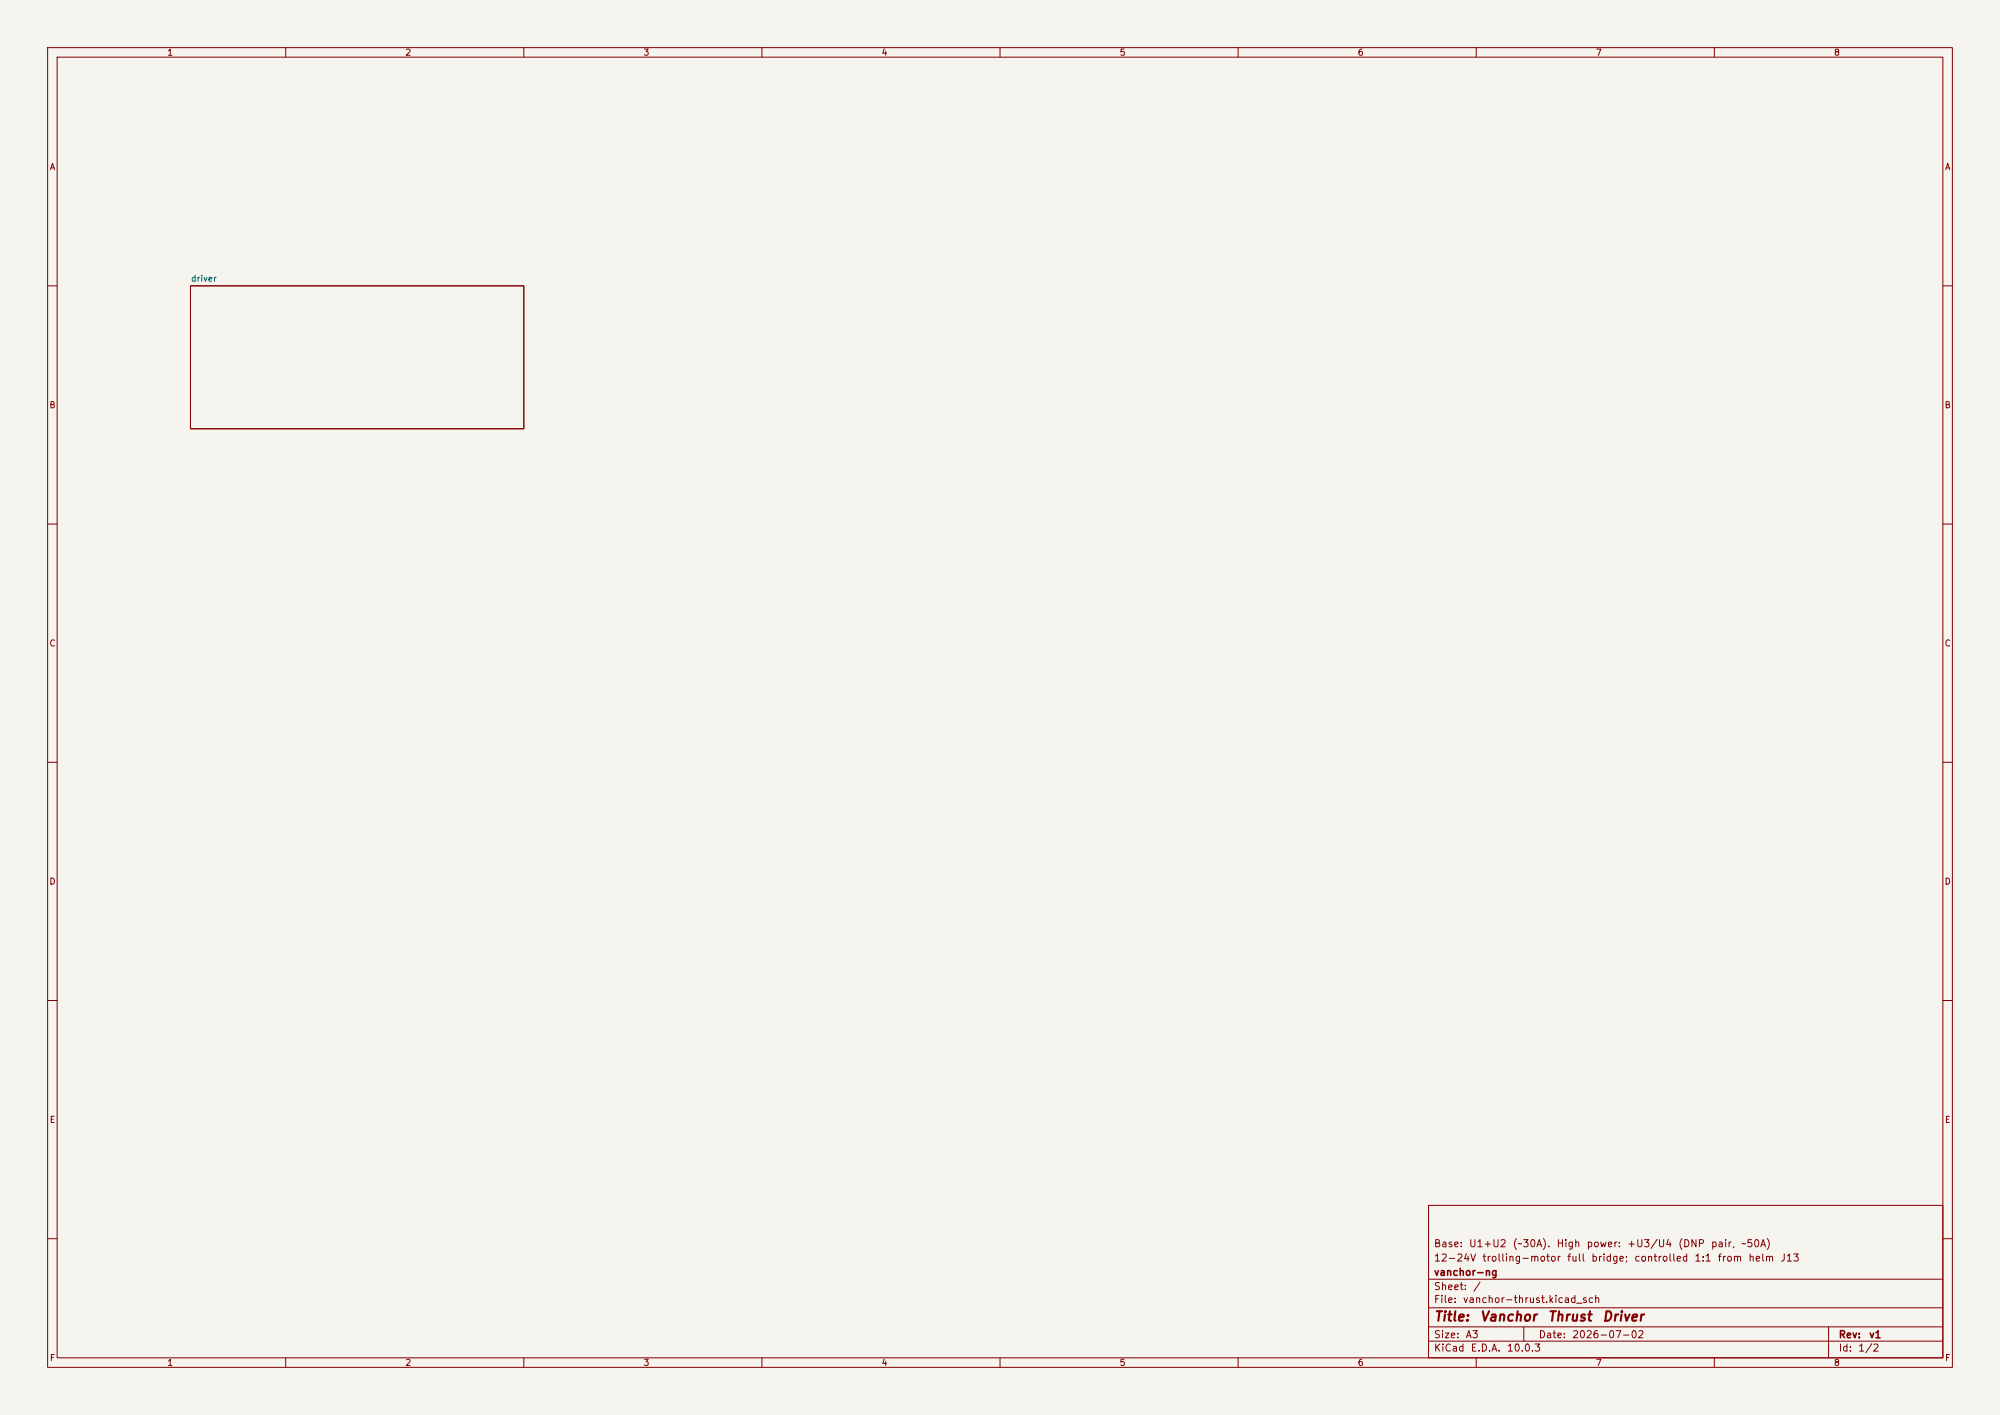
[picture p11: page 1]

Base: U1+U2 (~30A). High power: +U3/U4 (DNP pair, ~50A)
12-24V trolling-motor full bridge; controlled 1:1 from helm J13
vanchor-ng
Sheet: /
File: vanchor-thrust.kicad_sch
Title: Vanchor Thrust Driver

Size: A3 | Rev: v1
KiCad E.D.A. 10.0.3 | Id: 1/2 | F Date: 2026-07-02

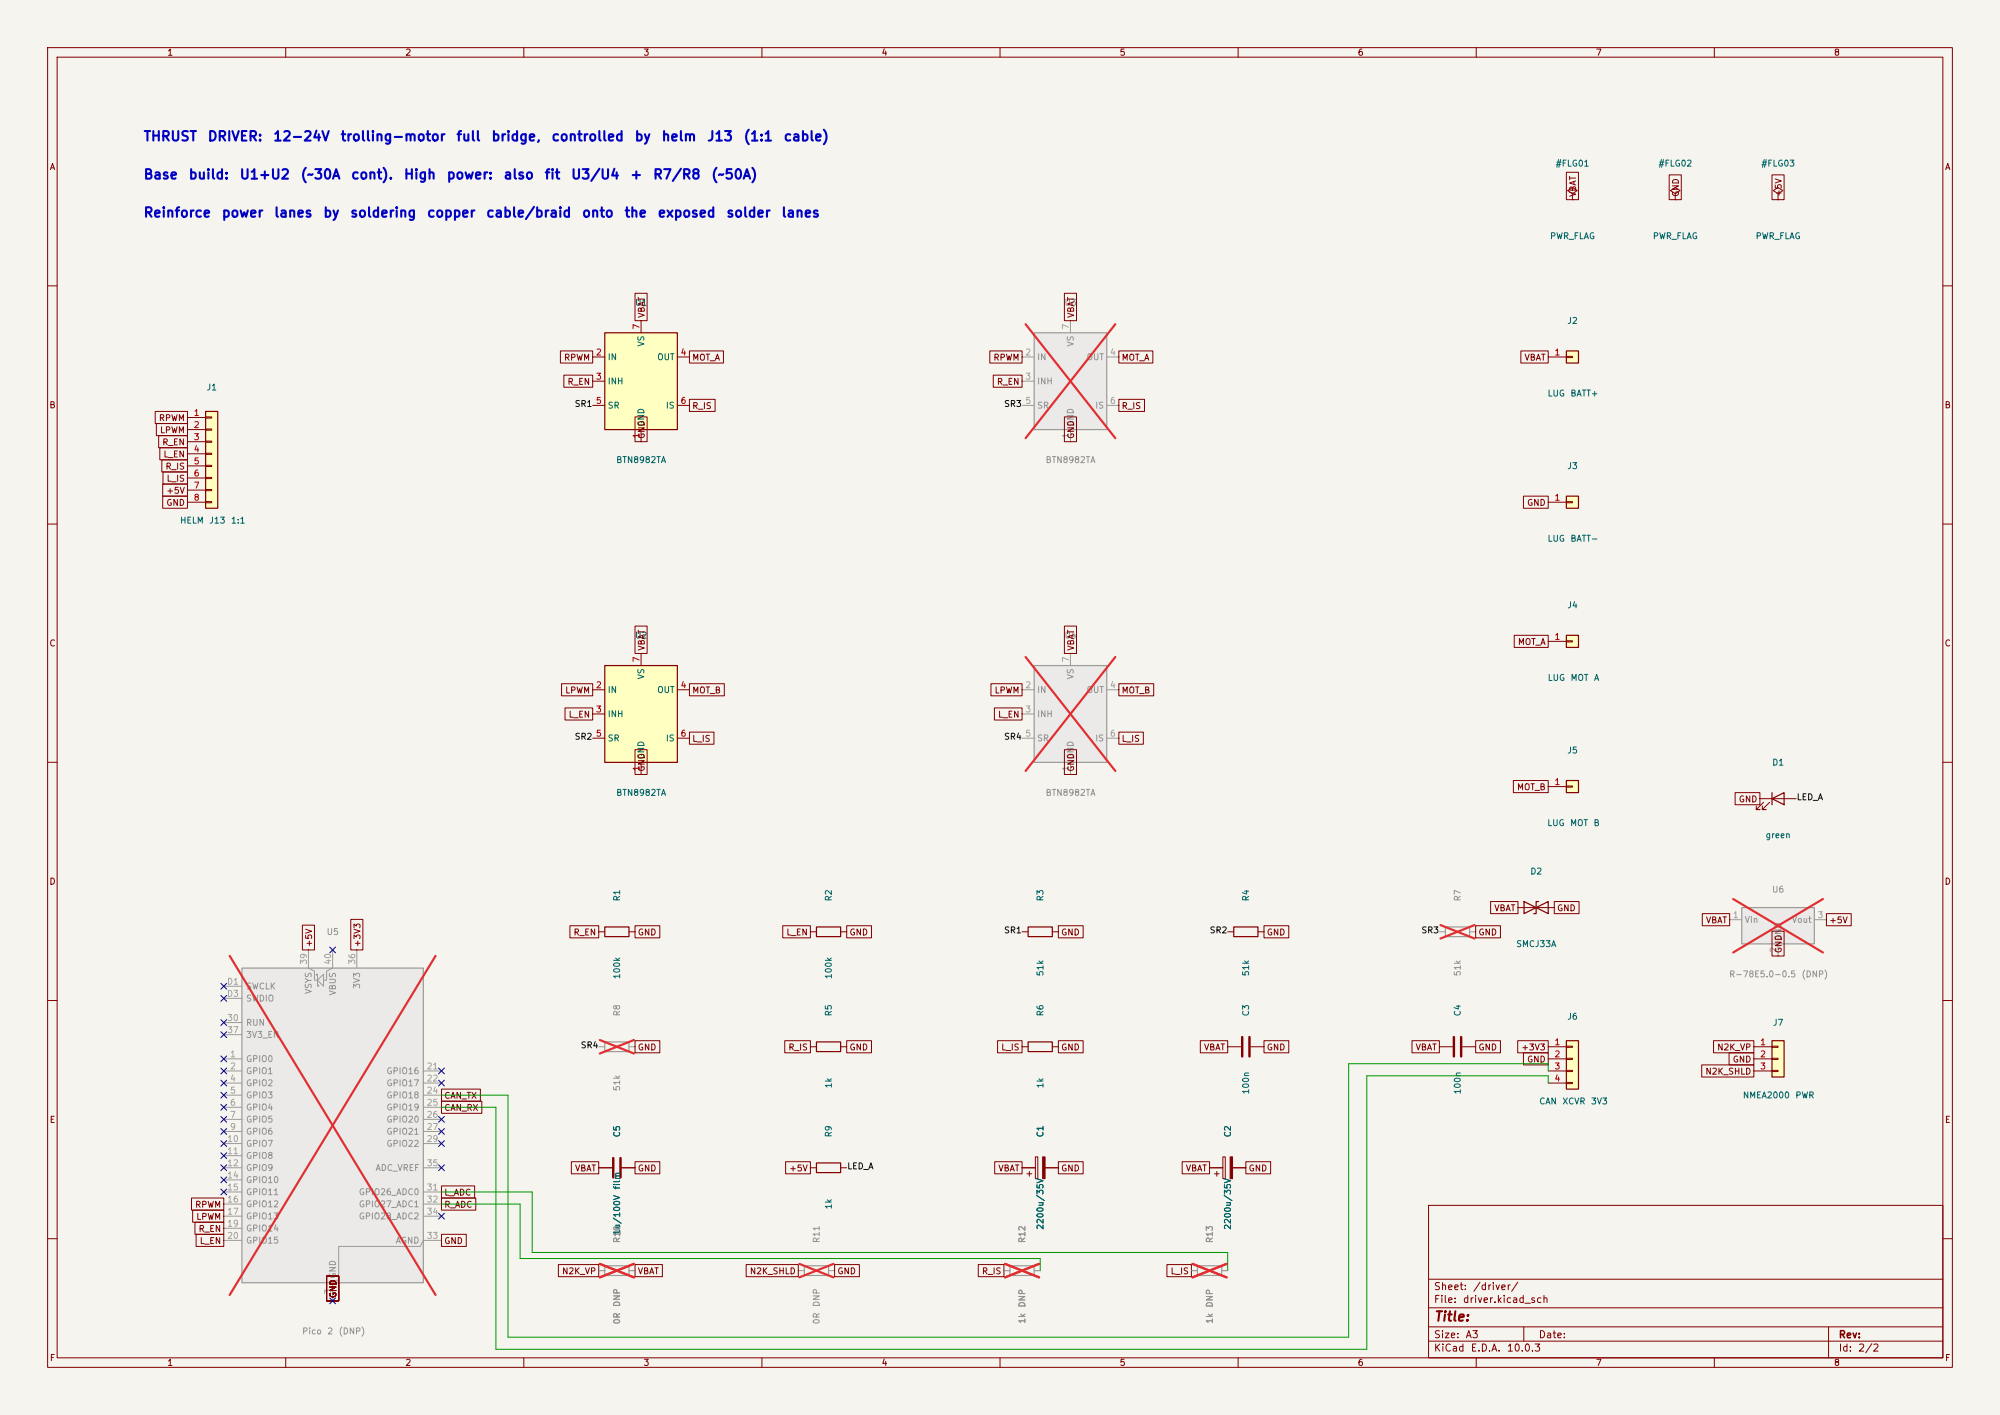
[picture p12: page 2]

Base build: U1+U2 (~30A cont). High power: also fit U3/U4 + R7/R8 (~50A)

SR3 Reinforce power lanes by soldering copper cable/braid onto the exposed solder lanes

Size: A3 | Rev:
KiCad E.D.A. 10.0.3 | Id: 2/2 | F Date:

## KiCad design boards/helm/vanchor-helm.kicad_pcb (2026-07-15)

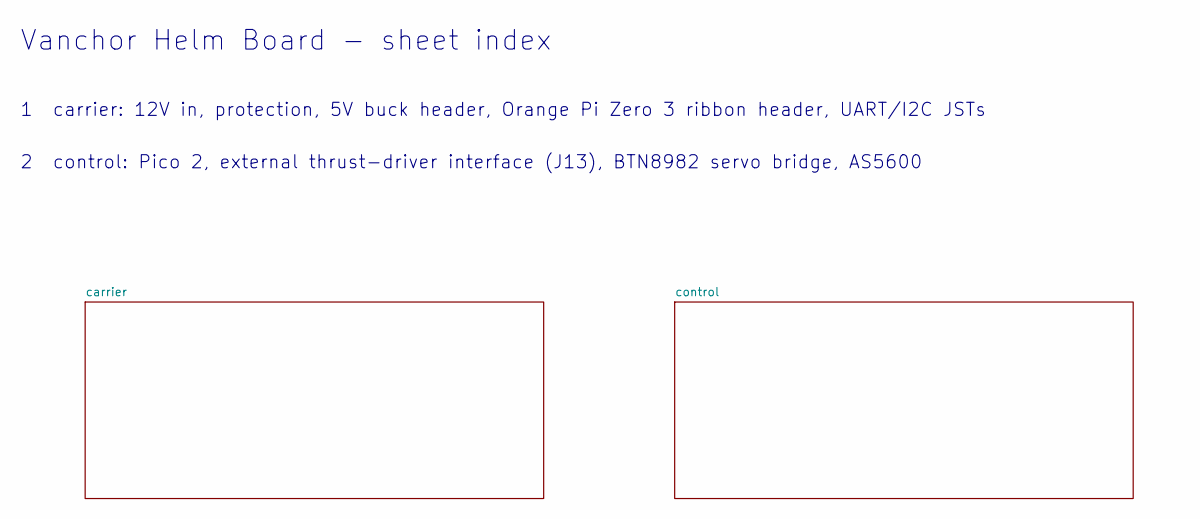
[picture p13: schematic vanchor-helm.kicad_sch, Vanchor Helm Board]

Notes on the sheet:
Vanchor Helm Board - sheet index
1 carrier: 12V in, protection, 5V buck header, Orange Pi Zero 3 ribbon header, UART/I2C JSTs
2 control: Pico 2, external thrust-driver interface (J13), BTN8982 servo bridge, AS5600

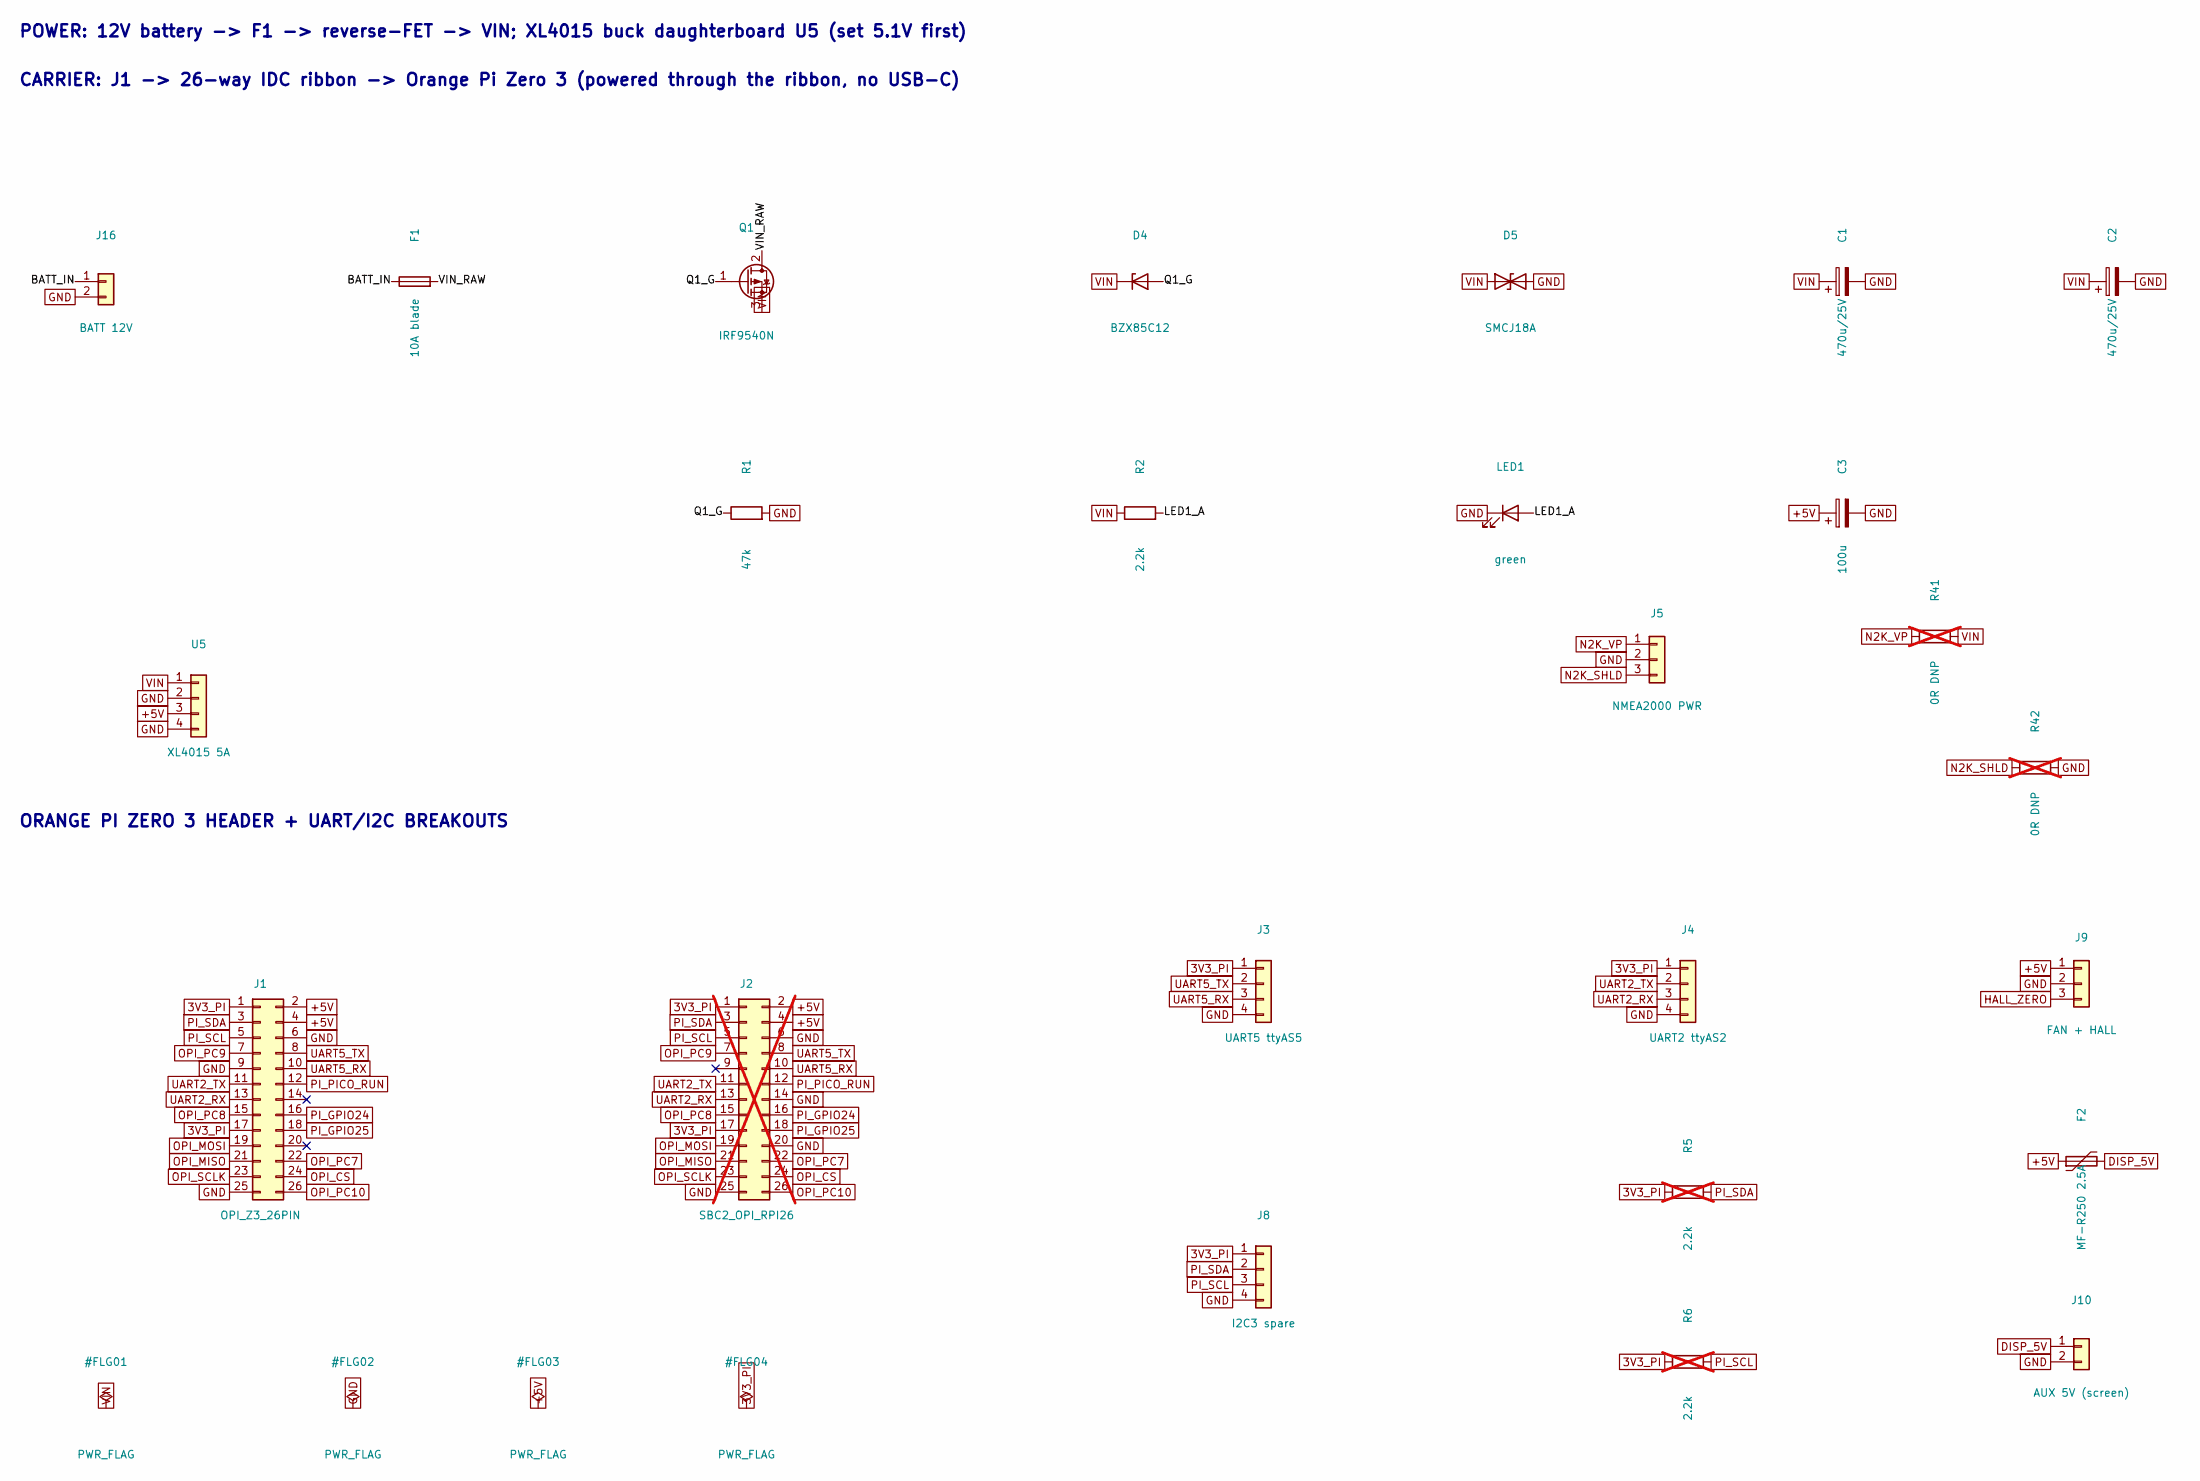
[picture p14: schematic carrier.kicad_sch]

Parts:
C1, C2: 470u/25V; CP_Radial_D12.5mm_P5.00mm; MPN EEU-FR1E471B
C3: 100u; CP_Radial_D6.3mm_P2.50mm; MPN EEU-FR1E101
D4: BZX85C12; D_DO-41_SOD81_P10.16mm_Horizontal; MPN BZX85C12-TAP
D5: SMCJ18A; D_SMC; MPN SMCJ18A
F1: 10A blade; Fuseholder_Blade_Mini_Keystone_3568; MPN 3568
F2: MF-R250 2.5A; MF-R250_Straight; MPN MF-R250
J1: OPI_Z3_26PIN; PinHeader_2x13_P2.54mm_Vertical; MPN 61302621121 (Wurth 2x13 2.54mm male hea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
J2: SBC2_OPI_RPI26; PinHeader_2x13_P2.54mm_Vertical; not fitted
J3: UART5 ttyAS5; JST_XH_B4B-XH-A_1x04_P2.50mm_Vertical; MPN JST B4B-XH-A(LF)(SN)
J4: UART2 ttyAS2; JST_XH_B4B-XH-A_1x04_P2.50mm_Vertical; MPN JST B4B-XH-A(LF)(SN)
J5: NMEA2000 PWR; JST_XH_B3B-XH-A_1x03_P2.50mm_Vertical; MPN JST B4B-XH-A(LF)(SN)
J8: I2C3 spare; JST_XH_B4B-XH-A_1x04_P2.50mm_Vertical; MPN JST B4B-XH-A(LF)(SN)
J9: FAN + HALL; PinHeader_1x03_P2.54mm_Vertical
J10: AUX 5V (screen); JST_XH_B2B-XH-A_1x02_P2.50mm_Vertical; MPN JST B2B-XH-A(LF)(SN)
J16: BATT 12V; TerminalBlock_CUI_TB007-508-02_1x02_P5.08mm_Horizontal
LED1: green; LED_D5.0mm
Q1: IRF9540N; TO-220-3_Vertical; MPN IRF9540NPBF
R1: 47k; R_Axial_DIN0207_L6.3mm_D2.5mm_P10.16mm_Horizontal
R2: 2.2k; R_Axial_DIN0207_L6.3mm_D2.5mm_P10.16mm_Horizontal
R5, R6: 2.2k; R_Axial_DIN0207_L6.3mm_D2.5mm_P10.16mm_Horizontal; not fitted
R41, R42: 0R DNP; R_Axial_DIN0207_L6.3mm_D2.5mm_P2.54mm_Vertical; not fitted
U5: XL4015 5A; XL4015_Module; MPN XL4015 5A module (AliExpress)

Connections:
3V3_PI: J1.1, J1.17, J2.1, J2.17, J3.1, J4.1, J8.1, R5.1, R6.1
+5V: C3.1, F2.1, J1.2, J1.4, J2.2, J2.4, J9.1, U5.3; also elsewhere on the board
/carrier/BATT_IN: F1.1, J16.1
/carrier/LED1_A: LED1.2 (A), R2.2
/carrier/Q1_G: D4.2 (A), Q1.1 (G), R1.1
/carrier/VIN_RAW: F1.2, Q1.2 (D)
DISP_5V: F2.2, J10.1
GND: C1.2, C2.2, C3.2, D5.2 (A2), J1.6, J1.9, J1.25, J2.6, J2.14, J2.20, J2.25, J3.4, J4.4, J5.2, J8.4, J9.2, J10.2, J16.2, LED1.1 (K), R1.2, R42.2, U5.2, U5.4; also elsewhere on the board
HALL_ZERO: J9.3; also elsewhere on the board
N2K_SHLD: J5.3, R42.1
N2K_VP: J5.1, R41.1
OPI_CS: J1.24, J2.24
OPI_MISO: J1.21, J2.21
OPI_MOSI: J1.19, J2.19
OPI_PC7: J1.22, J2.22
OPI_PC8: J1.15, J2.15
OPI_PC9: J1.7, J2.7
OPI_PC10: J1.26, J2.26
OPI_SCLK: J1.23, J2.23
PI_GPIO24: J1.16, J2.16; also elsewhere on the board
PI_GPIO25: J1.18, J2.18; also elsewhere on the board
PI_PICO_RUN: J1.12, J2.12; also elsewhere on the board
PI_SCL: J1.5, J2.5, J8.3, R6.2; also elsewhere on the board
PI_SDA: J1.3, J2.3, J8.2, R5.2; also elsewhere on the board
UART2_RX: J1.13, J2.13, J4.3
UART2_TX: J1.11, J2.11, J4.2
UART5_RX: J1.10, J2.10, J3.3
UART5_TX: J1.8, J2.8, J3.2
VIN: C1.1, C2.1, D4.1 (K), D5.1 (A1), Q1.3 (S), R2.1, R41.2, U5.1; also elsewhere on the board

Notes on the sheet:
POWER: 12V battery -> F1 -> reverse-FET -> VIN; XL4015 buck daughterboard U5 (set 5.1V first)
CARRIER: J1 -> 26-way IDC ribbon -> Orange Pi Zero 3 (powered through the ribbon, no USB-C)
ORANGE PI ZERO 3 HEADER + UART/I2C BREAKOUTS

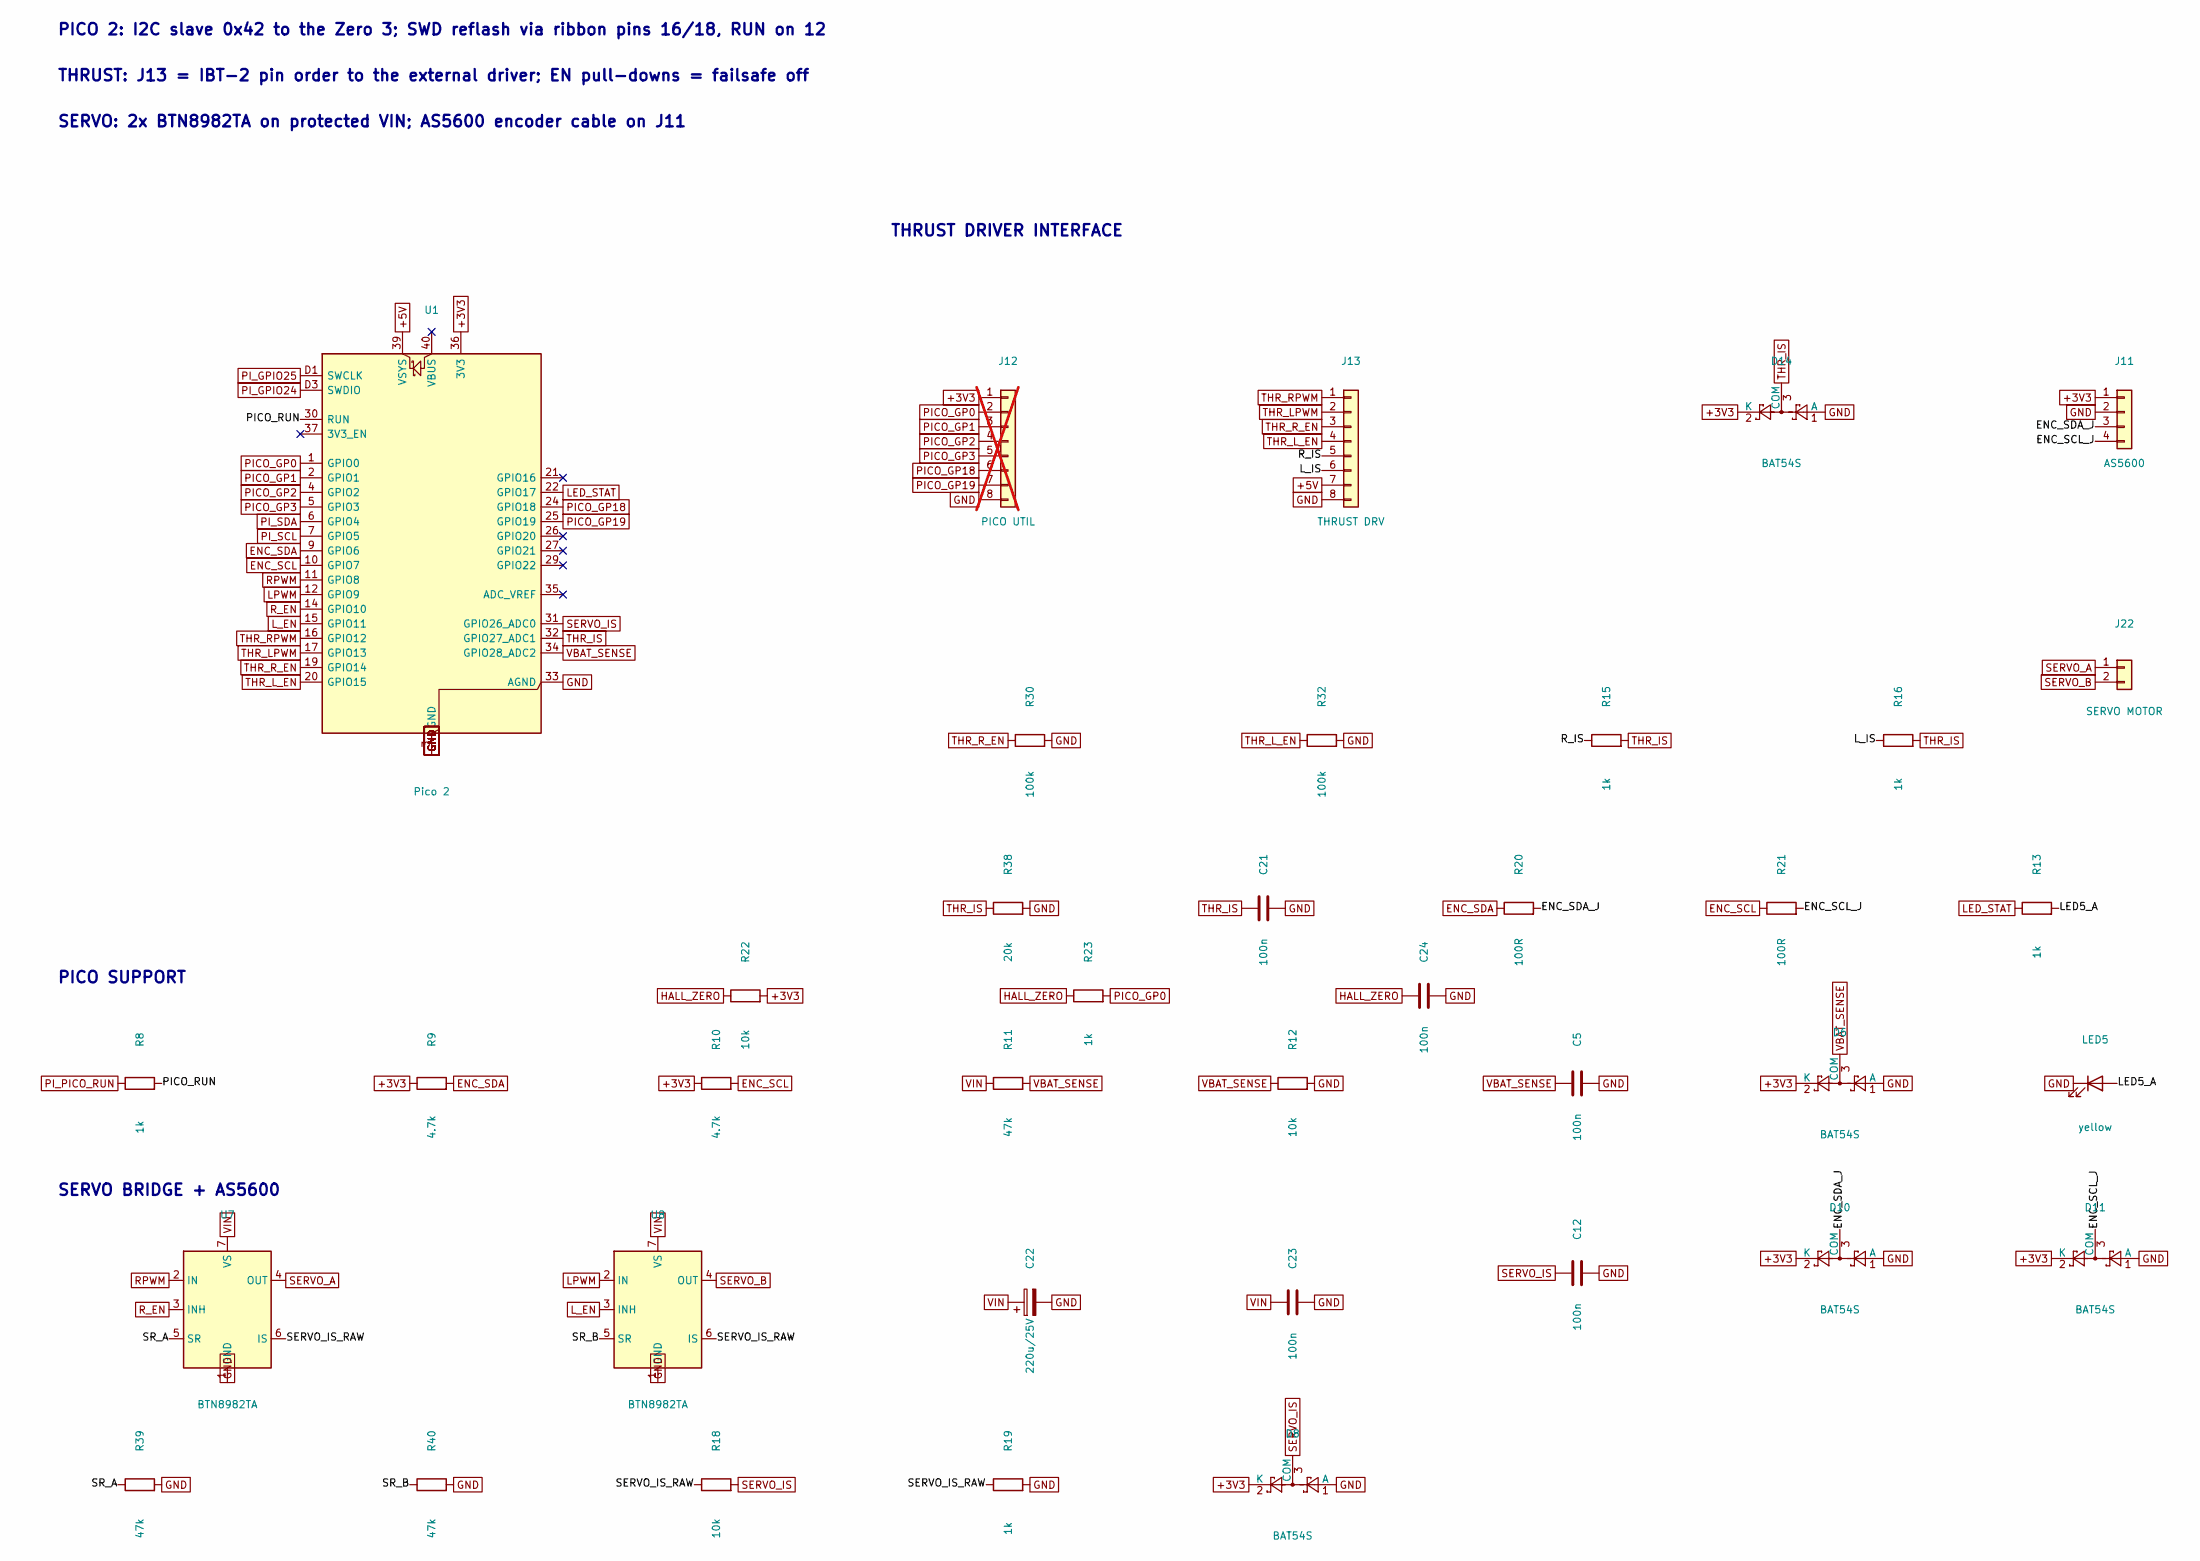
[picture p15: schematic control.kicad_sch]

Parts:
C5, C12, C21, C23: 100n; C_Disc_D5.0mm_W2.5mm_P5.00mm
C22: 220u/25V; CP_Radial_D8.0mm_P3.50mm; MPN EEU-FR1E221 (220uF/25V)
C24: 100n; C_0805_2012Metric
D6, D8, D10, D11, D14: BAT54S; SOT-23; MPN BAT54S,215
J11: AS5600; JST_XH_B4B-XH-A_1x04_P2.50mm_Vertical; MPN JST B4B-XH-A(LF)(SN)
J12: PICO UTIL; PinHeader_1x08_P2.54mm_Vertical; not fitted
J13: THRUST DRV; PinHeader_1x08_P2.54mm_Vertical
J22: SERVO MOTOR; TerminalBlock_CUI_TB007-508-02_1x02_P5.08mm_Horizontal; MPN CUI TB007-508-02
LED5: yellow; LED_D5.0mm
R8, R13, R15, R16, R19: 1k; R_Axial_DIN0207_L6.3mm_D2.5mm_P10.16mm_Horizontal
R9, R10: 4.7k; R_Axial_DIN0207_L6.3mm_D2.5mm_P10.16mm_Horizontal
R11, R39, R40: 47k; R_Axial_DIN0207_L6.3mm_D2.5mm_P10.16mm_Horizontal
R12, R18: 10k; R_Axial_DIN0207_L6.3mm_D2.5mm_P10.16mm_Horizontal
R20, R21: 100R; R_Axial_DIN0207_L6.3mm_D2.5mm_P10.16mm_Horizontal
R22: 10k; R_0805_2012Metric
R23: 1k; R_0805_2012Metric
R30, R32: 100k; R_Axial_DIN0207_L6.3mm_D2.5mm_P10.16mm_Horizontal
R38: 20k; R_Axial_DIN0207_L6.3mm_D2.5mm_P10.16mm_Horizontal
U1: Pico 2; RaspberryPi_Pico_TH_SWD; MPN Raspberry Pi Pico 2 (SC1632)
U7, U8: BTN8982TA; TO-263-7_TabPin4; MPN BTN8982TA

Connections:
+3V3: D6.2 (K), D8.2 (K), D10.2 (K), D11.2 (K), D14.2 (K), J11.1, J12.1, R9.1, R10.1, R22.2, U1.36 (3V3)
+5V: J13.7, U1.39 (VSYS); also elsewhere on the board
/control/ENC_SCL_J: D11.3 (COM), J11.4, R21.2
/control/ENC_SDA_J: D10.3 (COM), J11.3, R20.2
/control/LED5_A: LED5.2 (A), R13.2
/control/L_IS: J13.6, R16.1
/control/PICO_RUN: R8.2, U1.30 (RUN)
/control/R_IS: J13.5, R15.1
/control/SERVO_IS_RAW: R18.1, R19.1, U7.6 (IS), U8.6 (IS)
/control/SR_A: R39.1, U7.5 (SR)
/control/SR_B: R40.1, U8.5 (SR)
ENC_SCL: R10.2, R21.1, U1.10 (GPIO7)
ENC_SDA: R9.2, R20.1, U1.9 (GPIO6)
GND: C5.2, C12.2, C21.2, C22.2, C23.2, C24.2, D6.1 (A), D8.1 (A), D10.1 (A), D11.1 (A), D14.1 (A), J11.2, J12.8, J13.8, LED5.1 (K), R12.2, R19.2, R30.2, R32.2, R38.2, R39.2, R40.2, U1.3 (GND), U1.8 (GND), U1.13 (GND), U1.18 (GND), U1.23 (GND), U1.28 (GND), U1.33 (AGND), U1.38 (GND), U1.D2 (GND), U7.1 (GND), U8.1 (GND); also elsewhere on the board
HALL_ZERO: C24.1, R22.1, R23.1; also elsewhere on the board
LED_STAT: R13.1, U1.22 (GPIO17)
LPWM: U1.12 (GPIO9), U8.2 (IN)
L_EN: U1.15 (GPIO11), U8.3 (INH)
PICO_GP0: J12.2, R23.2, U1.1 (GPIO0)
PICO_GP1: J12.3, U1.2 (GPIO1)
PICO_GP2: J12.4, U1.4 (GPIO2)
PICO_GP3: J12.5, U1.5 (GPIO3)
PICO_GP18: J12.6, U1.24 (GPIO18)
PICO_GP19: J12.7, U1.25 (GPIO19)
PI_GPIO24: U1.D3 (SWDIO); also elsewhere on the board
PI_GPIO25: U1.D1 (SWCLK); also elsewhere on the board
PI_PICO_RUN: R8.1; also elsewhere on the board
PI_SCL: U1.7 (GPIO5); also elsewhere on the board
PI_SDA: U1.6 (GPIO4); also elsewhere on the board
RPWM: U1.11 (GPIO8), U7.2 (IN)
R_EN: U1.14 (GPIO10), U7.3 (INH)
SERVO_A: J22.1, U7.4 (OUT)
SERVO_B: J22.2, U8.4 (OUT)
SERVO_IS: C12.1, D8.3 (COM), R18.2, U1.31 (GPIO26_ADC0)
THR_IS: C21.1, D14.3 (COM), R15.2, R16.2, R38.1, U1.32 (GPIO27_ADC1)
THR_LPWM: J13.2, U1.17 (GPIO13)
THR_L_EN: J13.4, R32.1, U1.20 (GPIO15)
THR_RPWM: J13.1, U1.16 (GPIO12)
THR_R_EN: J13.3, R30.1, U1.19 (GPIO14)
VBAT_SENSE: C5.1, D6.3 (COM), R11.2, R12.1, U1.34 (GPIO28_ADC2)
VIN: C22.1, C23.1, R11.1, U7.7 (VS), U8.7 (VS); also elsewhere on the board

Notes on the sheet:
PICO 2: I2C slave 0x42 to the Zero 3; SWD reflash via ribbon pins 16/18, RUN on 12
THRUST: J13 = IBT-2 pin order to the external driver; EN pull-downs = failsafe off
SERVO: 2x BTN8982TA on protected VIN; AS5600 encoder cable on J11
THRUST DRIVER INTERFACE
PICO SUPPORT
SERVO BRIDGE + AS5600

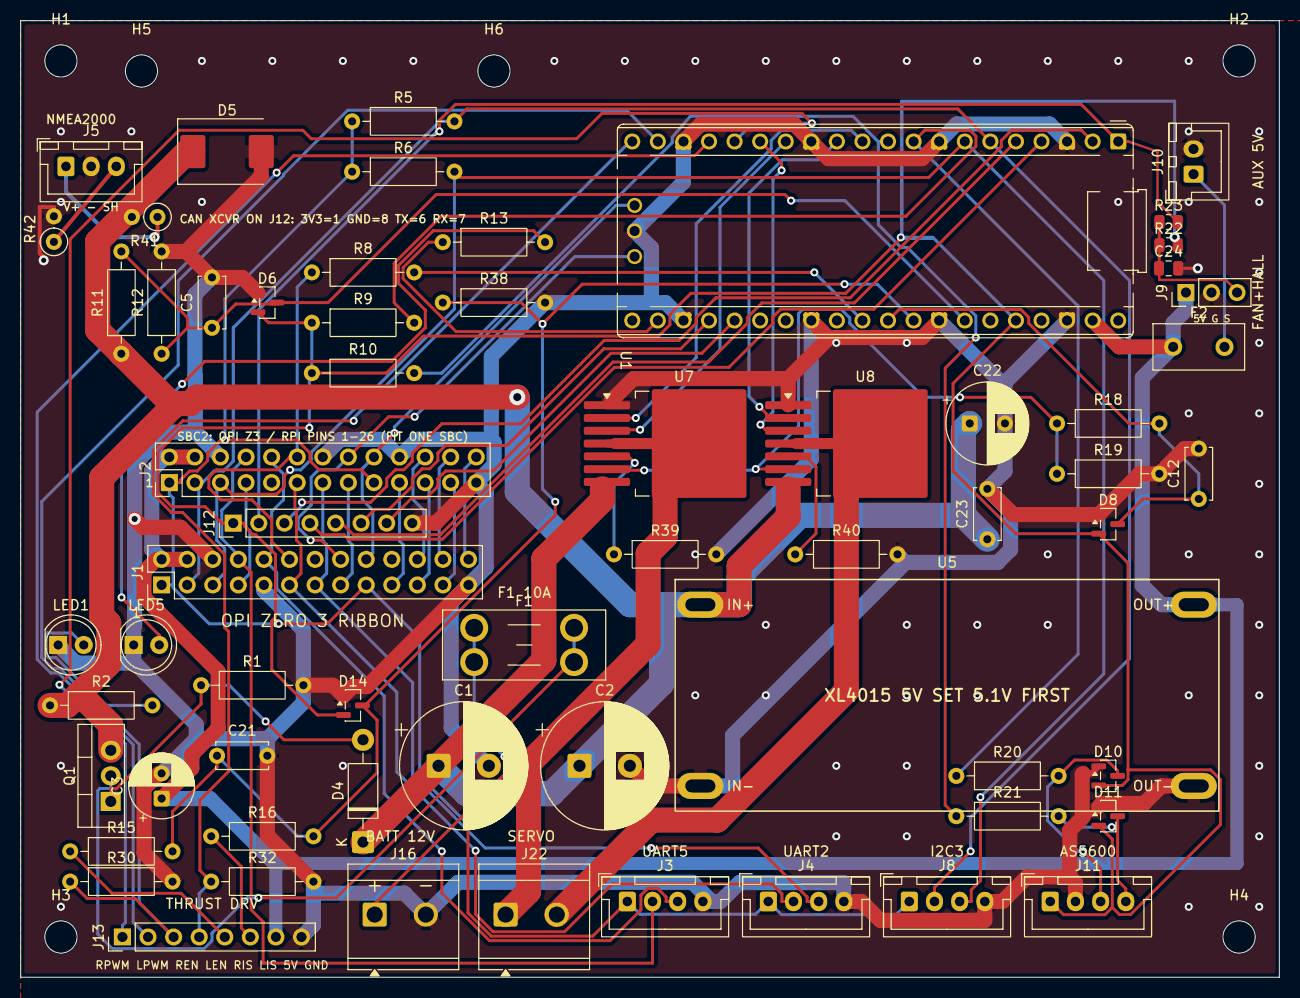
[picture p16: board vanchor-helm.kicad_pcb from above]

Board: 2 copper layers, 125.0 x 95.0 mm, 69 parts (0 on the bottom side), 61 nets.

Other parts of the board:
H1, H2, H3, H4, H5, H6: MountingHole_3.2mm_M3

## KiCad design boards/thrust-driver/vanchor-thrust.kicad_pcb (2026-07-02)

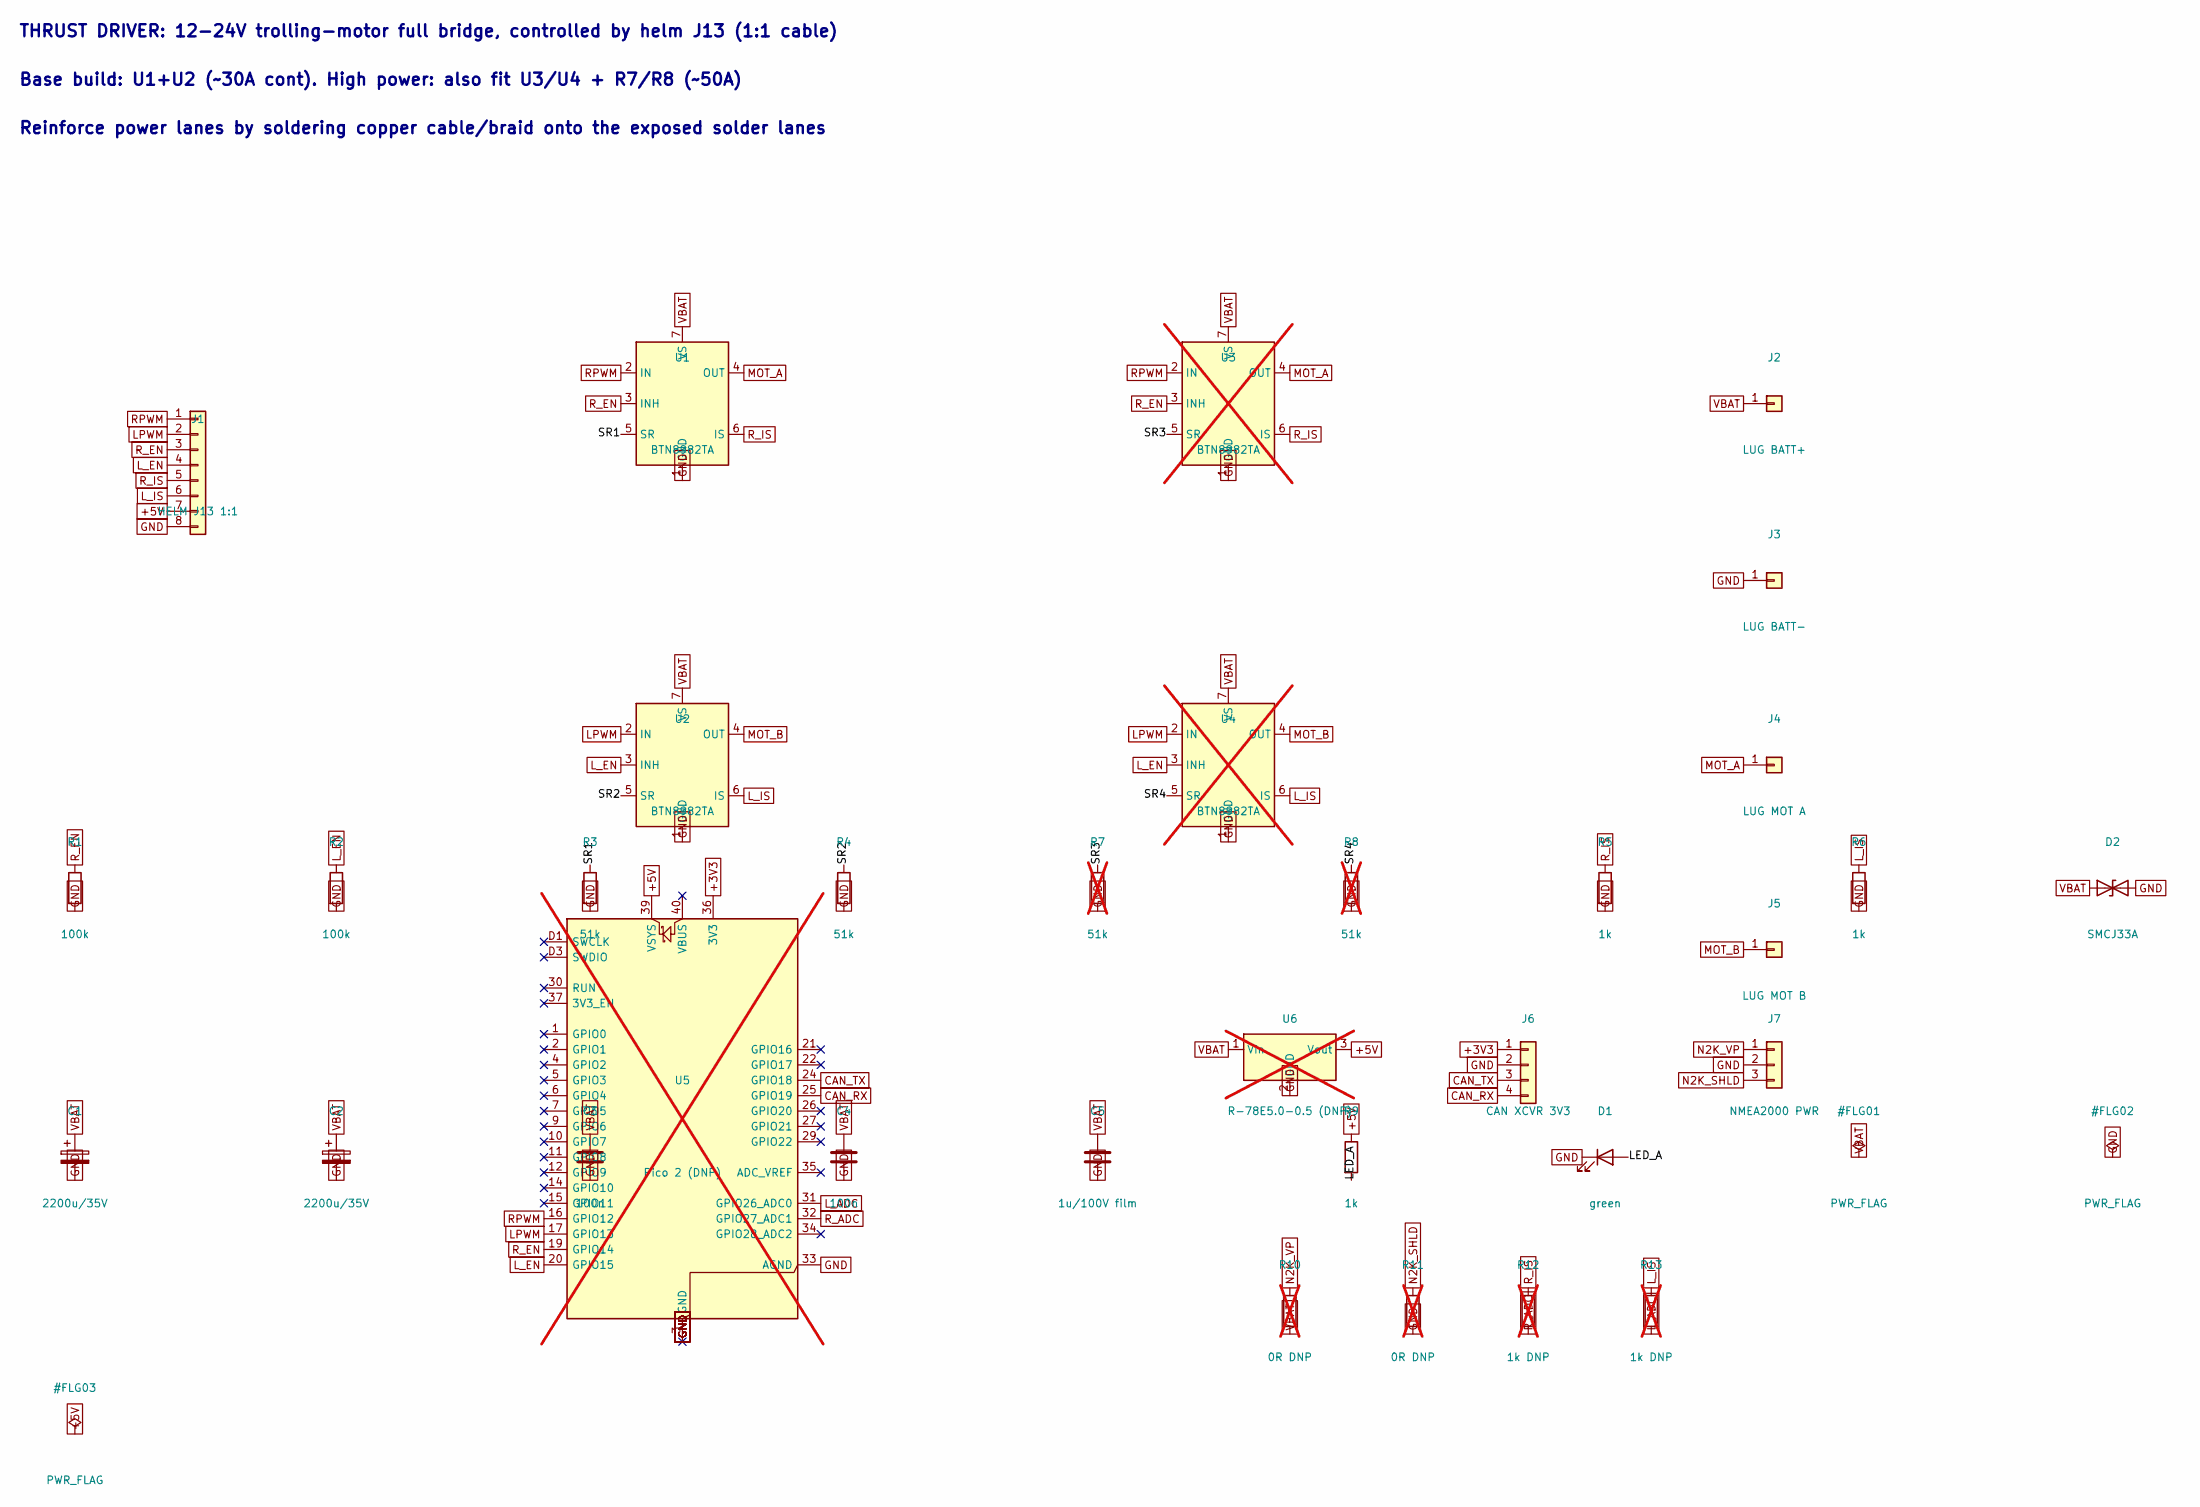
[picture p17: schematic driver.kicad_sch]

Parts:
C1, C2: 2200u/35V; CP_Radial_D18.0mm_P7.50mm
C3, C4: 100n; C_Disc_D5.0mm_W2.5mm_P5.00mm
C5: 1u/100V film; C_Rect_L13.0mm_W6.0mm_P10.00mm_FKS3_FKP3_MKS4
D1: green; LED_D5.0mm
D2: SMCJ33A; D_SMC
J1: HELM J13 1:1; PinHeader_1x08_P2.54mm_Vertical
J2: LUG BATT+; Lug_M5
J3: LUG BATT-; Lug_M5
J4: LUG MOT A; Lug_M5
J5: LUG MOT B; Lug_M5
J6: CAN XCVR 3V3; PinHeader_1x04_P2.54mm_Vertical
J7: NMEA2000 PWR; JST_XH_B3B-XH-A_1x03_P2.50mm_Vertical
R1, R2: 100k; R_Axial_DIN0207_L6.3mm_D2.5mm_P10.16mm_Horizontal
R3, R4: 51k; R_Axial_DIN0207_L6.3mm_D2.5mm_P10.16mm_Horizontal
R5, R6, R9: 1k; R_Axial_DIN0207_L6.3mm_D2.5mm_P10.16mm_Horizontal
R7, R8: 51k; R_Axial_DIN0207_L6.3mm_D2.5mm_P10.16mm_Horizontal; not fitted
R10, R11: 0R DNP; R_0805_2012Metric; not fitted
R12, R13: 1k DNP; R_0805_2012Metric; not fitted
U1, U2: BTN8982TA; TO-263-7_TabPin4
U3, U4: BTN8982TA; TO-263-7_TabPin4; not fitted
U5: Pico 2 (DNP); RaspberryPi_Pico_TH_SWD; not fitted
U6: R-78E5.0-0.5 (DNP); Converter_DCDC_TRACO_TSR-1_THT; not fitted

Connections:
+3V3: J6.1, U5.36 (3V3)
+5V: J1.7, R9.1, U5.39 (VSYS), U6.3 (Vout)
/driver/LED_A: D1.2 (A), R9.2
/driver/SR1: R3.1, U1.5 (SR)
/driver/SR2: R4.1, U2.5 (SR)
/driver/SR3: R7.1, U3.5 (SR)
/driver/SR4: R8.1, U4.5 (SR)
CAN_RX: J6.4, U5.25 (GPIO19)
CAN_TX: J6.3, U5.24 (GPIO18)
GND: C1.2, C2.2, C3.2, C4.2, C5.2, D1.1 (K), D2.2 (A2), J1.8, J3.1, J6.2, J7.2, R1.2, R2.2, R3.2, R4.2, R5.2, R6.2, R7.2, R8.2, R11.2, U1.1 (GND), U2.1 (GND), U3.1 (GND), U4.1 (GND), U5.3 (GND), U5.8 (GND), U5.13 (GND), U5.18 (GND), U5.23 (GND), U5.28 (GND), U5.33 (AGND), U5.38 (GND), U5.D2 (GND), U6.2 (GND)
LPWM: J1.2, U2.2 (IN), U4.2 (IN), U5.17 (GPIO13)
L_ADC: R13.2, U5.31 (GPIO26_ADC0)
L_EN: J1.4, R2.1, U2.3 (INH), U4.3 (INH), U5.20 (GPIO15)
L_IS: J1.6, R6.1, R13.1, U2.6 (IS), U4.6 (IS)
MOT_A: J4.1, U1.4 (OUT), U3.4 (OUT)
MOT_B: J5.1, U2.4 (OUT), U4.4 (OUT)
N2K_SHLD: J7.3, R11.1
N2K_VP: J7.1, R10.1
RPWM: J1.1, U1.2 (IN), U3.2 (IN), U5.16 (GPIO12)
R_ADC: R12.2, U5.32 (GPIO27_ADC1)
R_EN: J1.3, R1.1, U1.3 (INH), U3.3 (INH), U5.19 (GPIO14)
R_IS: J1.5, R5.1, R12.1, U1.6 (IS), U3.6 (IS)
VBAT: C1.1, C2.1, C3.1, C4.1, C5.1, D2.1 (A1), J2.1, R10.2, U1.7 (VS), U2.7 (VS), U3.7 (VS), U4.7 (VS), U6.1 (Vin)

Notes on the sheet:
THRUST DRIVER: 12-24V trolling-motor full bridge, controlled by helm J13 (1:1 cable)
Base build: U1+U2 (~30A cont). High power: also fit U3/U4 + R7/R8 (~50A)
Reinforce power lanes by soldering copper cable/braid onto the exposed solder lanes

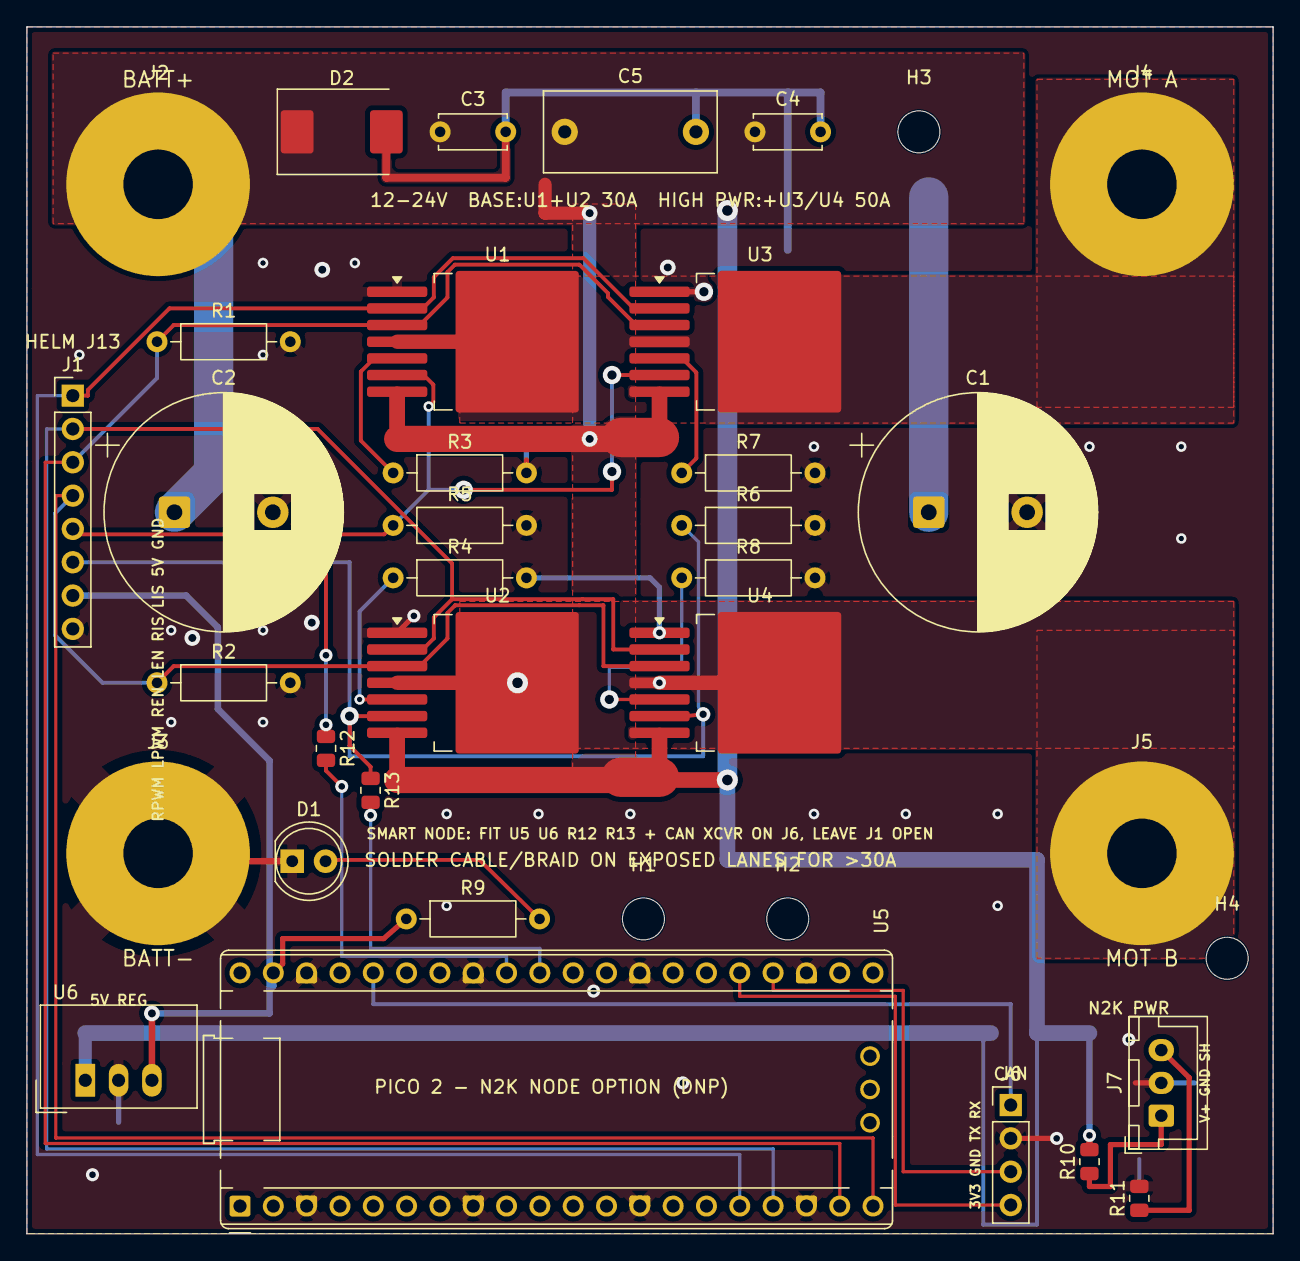
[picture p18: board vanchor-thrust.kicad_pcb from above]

Board: 2 copper layers, 95.0 x 92.0 mm, 37 parts (0 on the bottom side), 23 nets.

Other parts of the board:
H1, H2: MountingHole_3.2mm_M3
H3, H4: MountingHole; MountingHole_3.2mm_M3

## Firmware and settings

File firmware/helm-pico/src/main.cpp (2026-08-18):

/*
 * main.cpp — vanchor helm-board Pico 2 firmware.
 *
 * One Pico replaces both vanchor-ng Arduinos: it is the ENGINE board (thrust
 * via the external BTN8982 driver on J13) and the STEERING board (on-board
 * BTN8982 bridge + AS5600 azimuth encoder + hall zero index) speaking the
 * exact vanchor line protocol on TWO equivalent transports — USB-CDC and an
 * I2C slave tunnel at 0x42 on the SBC ribbon (docs/I2C-TUNNEL.md):
 *
 *   in :  CMD <pwm> <dir> <steer> [<seq>]*HH     (combined, the default)
 *         STEERD <deg> [<seq>]*HH                (v2.1 degrees-native)
 *         THRUST <pwm> <dir> [<seq>]*HH          (split thrust channel)
 *   out:  A <angle_deg> <ok> <wrap_pct> <seq>*HH   ~10 Hz
 *         E <pwm> <dir> <state> <seq>*HH           ~5 Hz
 *
 * Pi side: set motor_port to this board's CDC device (e.g. /dev/ttyACM0).
 * Baud is ignored on CDC. NMEA2000 (GP18/19) is intentionally absent for now.
 *
 * Safety chain: 800 ms protocol watchdog -> thrust slews to zero + steering
 * holds (worm self-locks); RP2350 hardware watchdog (2 s) reboots a wedged
 * firmware, and the board's 100 k pulldowns on every EN/INH pin keep both
 * bridges disabled through reset and reflash.
 */
#include <stdarg.h>
#include <stdio.h>
#include <string.h>

#include <stdlib.h>

#include "hardware/adc.h"
#include "hardware/clocks.h"
#include "hardware/flash.h"
#include "hardware/gpio.h"
#include "hardware/i2c.h"
#include "hardware/pwm.h"
#include "hardware/watchdog.h"
#include "pico/flash.h"
#include "pico/stdlib.h"

#include "board.h"
#include "config.h"

// Stamped by CMake from `git describe`; "dev" for out-of-tree builds.
#ifndef FW_VERSION
#define FW_VERSION "dev"
#endif
#if PICO_RP2040
#define MCU_NAME "pico"
#else
#define MCU_NAME "pico2"
#endif
#include "control_logic.h"
#include "i2c_tunnel.h"
#include "protocol_ext.h"

// ------------------------------------------------------------------ PWM -- //
// clk_sys / clkdiv 2 = PWM tick. Read at init instead of hardcoding 75 MHz:
// RP2350 runs 150 MHz but the RP2040 (plain Pico, a supported DIY target)
// runs 125 MHz -- a hardcoded tick made every PWM frequency come out x0.833
// there. wrap = tick/freq (at 62.5-75 MHz: 2 kHz -> 31249-37500, 16 kHz ->
// 3905-4687 — always >= 12-bit resolution, always < 65536).
static float PWM_TICK_HZ = 75.0e6f;   // overwritten in main() from clk_sys

static uint g_srvSlice, g_thrSlice;
static uint16_t g_srvWrap, g_thrWrap;

static uint16_t wrapForHz(float hz) {
  float w = PWM_TICK_HZ / hz - 1.0f;
  if (w > 65535.0f) w = 65535.0f;
  if (w < 1000.0f) w = 1000.0f;
  return (uint16_t)w;
}

static void pwmPairInit(uint pinA, uint pinB, uint *slice, uint16_t *wrap,
                        float hz) {
  gpio_set_function(pinA, GPIO_FUNC_PWM);
  gpio_set_function(pinB, GPIO_FUNC_PWM);
  *slice = pwm_gpio_to_slice_num(pinA);
  *wrap = wrapForHz(hz);
  pwm_set_clkdiv(*slice, 2.0f);
  pwm_set_wrap(*slice, *wrap);
  pwm_set_chan_level(*slice, PWM_CHAN_A, 0);
  pwm_set_chan_level(*slice, PWM_CHAN_B, 0);
  pwm_set_enabled(*slice, true);
}

// Servo bridge: signed -255..255. RPWM = channel A (GP8), LPWM = B (GP9).
static void servoDrive(int signedPwm) {
  uint32_t lvl =
      (uint32_t)((signedPwm < 0 ? -signedPwm : signedPwm)) * g_srvWrap / 255;
  pwm_set_chan_level(g_srvSlice, PWM_CHAN_A, signedPwm > 0 ? lvl : 0);
  pwm_set_chan_level(g_srvSlice, PWM_CHAN_B, signedPwm < 0 ? lvl : 0);
}

// Thrust bridge: magnitude 0..1 in `dir` (+1 F on RPWM/GP12, -1 R on LPWM).
static void thrustDrive(float mag, int8_t dir) {
  uint32_t lvl = (uint32_t)(mag * (float)g_thrWrap + 0.5f);
  pwm_set_chan_level(g_thrSlice, PWM_CHAN_A, dir > 0 ? lvl : 0);
  pwm_set_chan_level(g_thrSlice, PWM_CHAN_B, dir < 0 ? lvl : 0);
}

// Current-adaptive thrust PWM frequency (see board.h / driver README).
// Retunes wrap + level together; only when the schedule moved past the
// hysteresis band, so it never hunts and any sub-cycle blip is rare.
static float g_thrFreqHz = 16000.0f;
static void thrustRetune(float hystA, float amps, float mag, int8_t dir) {
  float ideal = thrustFreqHzForAmps(amps);
  float atNow = thrustFreqHzForAmps(amps + hystA);
  float atLow = thrustFreqHzForAmps(amps - hystA);
  // move only if the band no longer contains the current frequency
  if (g_thrFreqHz <= atNow - 1.0f || g_thrFreqHz >= atLow + 1.0f) {
    g_thrFreqHz = ideal;
    g_thrWrap = wrapForHz(g_thrFreqHz);
    pwm_set_wrap(g_thrSlice, g_thrWrap);
    thrustDrive(mag, dir);  // rescale duty to the new wrap immediately
  }
}

// ---------------------------------------------------------------- AS5600 -- //
static const uint8_t AS5600_ADDR = 0x36;
static const uint8_t AS5600_REG_STATUS = 0x0B;  // then RAW_ANGLE hi, lo

struct EncoderRead {
  bool ok;        // transaction succeeded AND magnet detected
  uint16_t raw;   // 12-bit angle
};

static EncoderRead as5600Read() {
  EncoderRead r{false, 0};
  uint8_t reg = AS5600_REG_STATUS;
  uint8_t buf[3];
  if (i2c_write_timeout_us(ENC_I2C, AS5600_ADDR, &reg, 1, true, 1000) != 1)
    return r;
  if (i2c_read_timeout_us(ENC_I2C, AS5600_ADDR, buf, 3, false, 1000) != 3)
    return r;
  // MD (0x20) magnet detected; ML (0x10) magnet too weak -> the angle is
  // unreliable even though MD may still be set. MH (too strong) still reads
  // a valid angle, so it is tolerated.
  bool magnet = (buf[0] & 0x20) != 0 && (buf[0] & 0x10) == 0;
  r.raw = (uint16_t)(((buf[1] & 0x0F) << 8) | buf[2]);
  r.ok = magnet;
  return r;
}

// If the slave wedges holding SDA low (mid-transfer power blip), every read
// times out forever and steering stays in feedback-hold until power cycle.
// The standard remedy: reclaim the pins as GPIO, clock 9 SCL pulses so the
// slave finishes whatever bit it thinks it is sending, then re-init.
static void as5600BusRecover() {
  i2c_deinit(ENC_I2C);
  gpio_set_function(PIN_ENC_SCL, GPIO_FUNC_SIO);
  gpio_set_function(PIN_ENC_SDA, GPIO_FUNC_SIO);
  gpio_set_dir(PIN_ENC_SCL, GPIO_OUT);
  gpio_set_dir(PIN_ENC_SDA, GPIO_IN);   // observe only; never drive SDA
  for (int i = 0; i < 9; i++) {
    gpio_put(PIN_ENC_SCL, 0);
    busy_wait_us(5);
    gpio_put(PIN_ENC_SCL, 1);
    busy_wait_us(5);
  }
  i2c_init(ENC_I2C, ENC_I2C_HZ);
  gpio_set_function(PIN_ENC_SDA, GPIO_FUNC_I2C);
  gpio_set_function(PIN_ENC_SCL, GPIO_FUNC_I2C);
}

// Debounced encoder health + glitch gate around the raw unwrap:
//  - a single bad transaction must not drop feedback-ok for a tick (integral
//    dump + drive chatter on a marginal bus);
//  - a single corrupted-but-"successful" read must not feed the accumulator
//    (one glitch sample can alias the multi-turn count);
//  - sustained failure (~50 ticks) attempts a bus recovery.
// The worm gear self-locks, so the head cannot move while the loop holds in
// feedback-loss -- the position is frozen across an outage and the shortest-
// path unwrap on recovery is trustworthy. (The hall index still re-trues the
// zero on every centre pass as the absolute backstop.)
static const int ENC_BAD_TO_UNHEALTHY = 3;
static const int ENC_GOOD_TO_HEALTHY = 3;
static const int ENC_BAD_TO_BUSCLEAR = 50;
static const int16_t ENC_MAX_DELTA_PER_TICK = 512;  // 45 deg shaft / 2 ms

// ------------------------------------------------------------- hall zero -- //
// Open-collector hall pulls GP0 LOW at the centre magnet. On each (debounced)
// falling edge the ISR snapshots a request; the control loop applies it so
// the zero capture is race-free with the encoder accumulator.
static volatile bool g_hallEvent = false;
static volatile uint32_t g_hallLastMs = 0;

static void hallIsr(uint gpio, uint32_t events) {
  (void)gpio;
  (void)events;
  uint32_t now = to_ms_since_boot(get_absolute_time());
  if (now - g_hallLastMs >= HALL_DEBOUNCE_MS) {
    g_hallLastMs = now;
    g_hallEvent = true;
  }
}

// ------------------------------------------------------------------- ADC -- //
static float adcVolts(uint input) {
  adc_select_input(input);
  (void)adc_read();  // settle after mux switch
  uint32_t acc = 0;
  for (int i = 0; i < 4; i++) acc += adc_read();
  return (float)acc / 4.0f * ADC_VREF_V / 4096.0f;
}

// ------------------------------------------------------------ serial I/O -- //
// One accumulator per transport so interleaved half-lines cannot mix.
struct LineAccum {
  char buf[VANCHOR_LINE_MAX];
  uint8_t len = 0;
  bool poisoned = false;  // overflowed or NUL-corrupted: discard to newline
};
static LineAccum g_usbAcc, g_i2cAcc;

// Every outbound line goes to BOTH transports: USB always, the I2C tunnel
// whenever a master has polled recently (so the FIFO never fills with stale
// telemetry when nobody is on the bus).
static void sendLine(char *buf, size_t cap) {
  vanchorAppendCrc(buf, (unsigned int)cap);
  fputs(buf, stdout);
  fputs("\r\n", stdout);
  fflush(stdout);
  i2cTunnelSendLine(buf, to_ms_since_boot(get_absolute_time()));
}

// -------------------------------------------------------------- config --- //
static HelmConfig g_cfg;

// Persisted image lives in the LAST 4 kB flash sector, far above the code.
#define CONF_FLASH_OFFSET (PICO_FLASH_SIZE_BYTES - FLASH_SECTOR_SIZE)
#define CONF_WRITE_MIN_MS 2000  // wear/abuse guard between erase cycles

static const uint8_t *confFlashPtr() {
  return (const uint8_t *)(XIP_BASE + CONF_FLASH_OFFSET);
}

static void confFlashJob(void *param) {
  // Runs with IRQs off / other core locked out (flash_safe_execute).
  flash_range_erase(CONF_FLASH_OFFSET, FLASH_SECTOR_SIZE);
  flash_range_program(CONF_FLASH_OFFSET, (const uint8_t *)param,
                      FLASH_PAGE_SIZE);
}

// Persist `c`. Returns 1 written+verified, 0 flash already identical (no
// erase happened), -1 rate-limited, -2 flash error/verify mismatch.
static int confPersist(const HelmConfig &c, uint32_t nowMs) {
  static uint32_t lastWriteMs = 0;
  static uint8_t img[FLASH_PAGE_SIZE];
  memset(img, 0xFF, sizeof img);
  confSerialize(c, img);
  if (memcmp(confFlashPtr(), img, sizeof img) == 0) return 0;  // diff guard
  if (lastWriteMs != 0 && (nowMs - lastWriteMs) < CONF_WRITE_MIN_MS) return -1;
  watchdog_update();  // the erase stalls everything for tens of ms
  if (flash_safe_execute(confFlashJob, img, 500) != PICO_OK) return -2;
  lastWriteMs = nowMs;
  return memcmp(confFlashPtr(), img, sizeof img) == 0 ? 1 : -2;
}

// The config currently stored in flash (defaults where absent/invalid).
static HelmConfig confStored() {
  HelmConfig c;
  confDeserialize(c, confFlashPtr(), FLASH_PAGE_SIZE);
  return c;
}

// -------------------------------------------------------------- state ---- //
static float g_wantThrust = 0.0f;   // 0..1 requested magnitude
static int8_t g_wantDir = +1;
// PER-CHANNEL watchdogs. With the split channels (STEERD + THRUST are
// separate Pi-side writers) a single shared timestamp would let a live
// steering stream mask a dead thrust writer -- prop stuck at the last pwm
// indefinitely. On the two-Arduino system each board's own watchdog covered
// its channel; one board must keep that per-channel guarantee.
static uint32_t g_lastThrustMs = 0;  // last valid CMD or THRUST
static uint32_t g_lastSteerMs = 0;   // last valid CMD or STEERD
static bool g_everCommanded = false;
static int g_lastSeq = -1;

static int g_confLoaded = -1;  // keys applied from flash at boot (-1 = none)
static ThrustGate g_thrust;
static SteeringLoop g_steer;
static EncoderUnwrap g_enc;
static int32_t g_zeroAccum = 0;     // encoder counts at azimuth zero
static bool g_feedbackOk = false;
static float g_angleDeg = 0.0f;
static float g_thrAmpsFilt = 0.0f;
static float g_srvAmpsFilt = 0.0f;

static void confReply(const char *fmt, ...) {
  char buf[VANCHOR_LINE_MAX];
  va_list ap;
  va_start(ap, fmt);
  vsnprintf(buf, sizeof buf, fmt, ap);
  va_end(ap);
  sendLine(buf, sizeof buf);
}

// "CONF <key> <value>"  -> RAM only.
// "CONFW <key> <value>" -> RAM + persist THAT KEY into the stored image.
// "CONFSAVE"            -> persist the whole active config.
// "CONFDUMP"            -> one "C <key> <ram> <stored>" line per key.
// Config traffic never feeds the motor watchdog or the heartbeat seq.
static void handleConf(const char *line, uint32_t nowMs) {
  const char *p = line + 4;
  bool writeThrough = false;
  if (strncmp(p, "SAVE", 4) == 0) {
    int r = confPersist(g_cfg, nowMs);
    confReply(r == 1   ? "C saved"
              : r == 0 ? "C clean"
              : r == -1 ? "C err ratelimit"
                        : "C err flash");
    return;
  }
  if (strncmp(p, "DUMP", 4) == 0) {
    HelmConfig stored = confStored();
    for (int i = 0; i < CONF_NKEYS; i++)
      confReply("C %s %g %g", CONF_KEYS[i].name, (double)confGet(g_cfg, i),
                (double)confGet(stored, i));
    confReply("C end %d", CONF_NKEYS);
    return;
  }
  if (*p == 'W') {
    writeThrough = true;
    p++;
  }
  if (*p != ' ') return;  // unknown CONFx token: ignore
  while (*p == ' ') p++;
  char key[24];
  size_t k = 0;
  while (*p && *p != ' ' && k + 1 < sizeof key) key[k++] = *p++;
  key[k] = '\0';
  int idx = confFind(key);
  if (idx < 0) {
    confReply("C err key %s", key);
    return;
  }
  while (*p == ' ') p++;
  char *endp = nullptr;
  float v = strtof(p, &endp);
  if (endp == p || !confSet(g_cfg, idx, v)) {
    confReply("C err range %s", key);
    return;
  }
  if (!writeThrough) {
    confReply("C ok %s %g", key, (double)v);
    return;
  }
  // Write-through: update ONLY this key in the stored image, so other
  // in-RAM experiments stay temporary.
  HelmConfig stored = confStored();
  confSet(stored, idx, v);
  int r = confPersist(stored, nowMs);
  confReply(r == 1   ? "C wrote %s %g"
            : r == 0 ? "C clean %s %g"
            : r == -1 ? "C err ratelimit %s"
                      : "C err flash %s",
            key, (double)v);
}

// "INFO" -> identity/version/health snapshot as "I ..." lines (the Pi's
// feedback parsers ignore them; a bench console reads them directly).
static void handleInfo(uint32_t nowMs) {
  confReply("I fw %s board helm-4.2 mcu " MCU_NAME, FW_VERSION);
  confReply("I proto 2.1 crc %d wdog %d", VANCHOR_REQUIRE_CRC,
            VANCHOR_WATCHDOG_MS);
  confReply("I conf %d keys %d flash %s", CONF_VERSION, CONF_NKEYS,
            g_confLoaded < 0 ? "defaults" : "stored");
  confReply("I i2c 0x%02X v%d active %d", TUN_I2C_ADDR, 1,
            i2cTunnelActive(nowMs) ? 1 : 0);
  confReply("I up %lu vbat %.1f ang %.1f fb %d", nowMs / 1000,
            (double)(adcVolts(2) * g_cfg.calVbat), (double)g_angleDeg,
            g_feedbackOk ? 1 : 0);
  confReply("I end 5");
}

static void handleLine(char *line, uint32_t nowMs) {
  if (!vanchorAcceptLine(line)) return;  // CRC gate (VANCHOR_REQUIRE_CRC)
  if (strcmp(line, "INFO") == 0) {
    handleInfo(nowMs);
    return;
  }
  if (strncmp(line, "CONF", 4) == 0) {
    handleConf(line, nowMs);
    return;
  }
  int pwm, steer, seq;
  char dir;
  float deg;
  if (vanchorParseCmd(line, &pwm, &dir, &steer, &seq)) {
    g_wantThrust = (float)pwm / 255.0f;
    g_wantDir = (dir == 'R') ? -1 : +1;
    g_steer.setTarget(g_cfg, ((float)steer / 100.0f) * g_cfg.steerFull);
    g_lastThrustMs = nowMs;
    g_lastSteerMs = nowMs;
  } else if (vanchorParseSteerDeg(line, &deg, &seq)) {
    g_steer.setTarget(g_cfg, deg);
    g_lastSteerMs = nowMs;
  } else if (vanchorParseThrust(line, &pwm, &dir, &seq)) {
    g_wantThrust = (float)pwm / 255.0f;
    g_wantDir = (dir == 'R') ? -1 : +1;
    g_lastThrustMs = nowMs;
  } else {
    return;  // unknown token: ignore, do not feed the watchdog
  }
  g_lastSeq = seq;
  g_everCommanded = true;
}
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
int main() {
  stdio_init_all();
  PWM_TICK_HZ = (float)clock_get_hz(clk_sys) / 2.0f;  // clkdiv 2 in pwmPairInit

  // Bridge enables as plain outputs, LOW (disabled) until first command.
  const uint enPins[] = {PIN_SRV_R_EN, PIN_SRV_L_EN, PIN_THR_R_EN,
                         PIN_THR_L_EN};
  for (uint p : enPins) {
    gpio_init(p);
    gpio_put(p, 0);
    gpio_set_dir(p, GPIO_OUT);
  }
  gpio_init(PIN_LED_STAT);
  gpio_set_dir(PIN_LED_STAT, GPIO_OUT);

  pwmPairInit(PIN_SRV_RPWM, PIN_SRV_LPWM, &g_srvSlice, &g_srvWrap, SRV_PWM_HZ);
  pwmPairInit(PIN_THR_RPWM, PIN_THR_LPWM, &g_thrSlice, &g_thrWrap, g_thrFreqHz);

  // AS5600 on I2C1 (board has the pull-ups).
  i2c_init(ENC_I2C, ENC_I2C_HZ);
  gpio_set_function(PIN_ENC_SDA, GPIO_FUNC_I2C);
  gpio_set_function(PIN_ENC_SCL, GPIO_FUNC_I2C);

  // I2C tunnel to the SBC (slave 0x42 on the ribbon's I2C3).
  i2cTunnelInit();

  // Hall zero input. The PCB has a 10k pull-up + RC; enable the internal
  // pull-up too so a bare-Pico DIY build with an open-collector hall does
  // not float (spurious re-zero IRQs). Harmless in parallel with the 10k.
  gpio_init(PIN_HALL_ZERO);
  gpio_set_dir(PIN_HALL_ZERO, GPIO_IN);
  gpio_pull_up(PIN_HALL_ZERO);
  gpio_set_irq_enabled_with_callback(PIN_HALL_ZERO, GPIO_IRQ_EDGE_FALL, true,
                                     &hallIsr);

  adc_init();
  adc_gpio_init(PIN_ADC_SERVO_IS);
  adc_gpio_init(PIN_ADC_THR_IS);
  adc_gpio_init(PIN_ADC_VBAT);

  // Stored configuration (defaults when the sector is blank/invalid).
  g_confLoaded = confDeserialize(g_cfg, confFlashPtr(), FLASH_PAGE_SIZE);

  // Prime the encoder and hold the current heading (steering.ino boot rule).
  EncoderRead er = as5600Read();
  if (er.ok) {
    g_enc.feed(er.raw);
    g_feedbackOk = true;
  }
  g_steer.targetDeg = g_enc.degrees(g_cfg, g_zeroAccum);
  g_steer.stallRefDeg = g_steer.targetDeg;

  uint32_t bootMs = to_ms_since_boot(get_absolute_time());
  g_lastThrustMs = bootMs;
  g_lastSteerMs = bootMs;
  uint32_t lastTickMs = bootMs;
  uint32_t lastAMs = bootMs, lastEMs = bootMs;
  absolute_time_t nextTick = make_timeout_time_us(CONTROL_TICK_US);

  // Hardware watchdog: reboots a wedged loop; the EN pulldowns keep both
  // bridges safe through the reboot.
  watchdog_enable(2000, true);

  for (;;) {
    watchdog_update();
    uint32_t nowMs = to_ms_since_boot(get_absolute_time());
    pollSerial(nowMs);

    if (!time_reached(nextTick)) continue;
    nextTick = make_timeout_time_us(CONTROL_TICK_US);

    float dtS = (float)(nowMs - lastTickMs) / 1000.0f;
    if (dtS <= 0.0f) dtS = 0.001f;
    lastTickMs = nowMs;

    // --- sensors --------------------------------------------------------- //
    er = as5600Read();
    static int encBadStreak = 0, encGoodStreak = 0;
    bool sampleOk = er.ok;
    if (sampleOk && g_enc.primed) {
      // Glitch gate: a shaft step > 45 deg in one 2 ms tick is physically
      // impossible (worm drive) -- corrupted read; do not feed the unwrap.
      int16_t d = (int16_t)(((er.raw - g_enc.prevRaw + ENC_COUNTS_PER_REV / 2) &
                             (ENC_COUNTS_PER_REV - 1)) -
                            ENC_COUNTS_PER_REV / 2);
      if (d > ENC_MAX_DELTA_PER_TICK || d < -ENC_MAX_DELTA_PER_TICK)
        sampleOk = false;
    }
    if (sampleOk) {
      g_enc.feed(er.raw);
      encBadStreak = 0;
      if (encGoodStreak < ENC_GOOD_TO_HEALTHY) encGoodStreak++;
      if (encGoodStreak >= ENC_GOOD_TO_HEALTHY) g_feedbackOk = true;
    } else {
      encGoodStreak = 0;
      if (encBadStreak < 1000000) encBadStreak++;
      if (encBadStreak >= ENC_BAD_TO_UNHEALTHY) g_feedbackOk = false;
      if (encBadStreak == ENC_BAD_TO_BUSCLEAR) as5600BusRecover();
    }
    if (g_hallEvent) {  // magnet edge: this position IS the hall reference
      g_hallEvent = false;
      float hallDeg = g_cfg.hallDeg * (g_cfg.encInvert >= 0.5f ? -1.0f : 1.0f);
      g_zeroAccum = g_enc.accum -
                    (int32_t)(hallDeg / 360.0f * g_cfg.encGear *
                              (float)ENC_COUNTS_PER_REV);
    }
    g_angleDeg = g_enc.degrees(g_cfg, g_zeroAccum);

    float thrAmps = adcVolts(1) / g_cfg.calThrVpa;
    float srvAmps = adcVolts(0) / g_cfg.calSrvVpa;
    g_thrAmpsFilt += 0.1f * (thrAmps - g_thrAmpsFilt);
    g_srvAmpsFilt += 0.1f * (srvAmps - g_srvAmpsFilt);

    // --- control --------------------------------------------------------- //
    bool thrustFailsafe = (nowMs - g_lastThrustMs) > VANCHOR_WATCHDOG_MS;
    bool steerFailsafe = (nowMs - g_lastSteerMs) > VANCHOR_WATCHDOG_MS;

    // Bridges stay disabled until the Pi has spoken once (defence in depth
    // on top of the board pulldowns); after that they are held enabled so
    // failsafe can still brake/hold.
    bool enable = g_everCommanded;
    gpio_put(PIN_SRV_R_EN, enable);
    gpio_put(PIN_SRV_L_EN, enable);
    gpio_put(PIN_THR_R_EN, enable);
    gpio_put(PIN_THR_L_EN, enable);

    float mag = g_thrust.update(g_cfg, g_wantThrust, g_wantDir, thrustFailsafe,
                                nowMs, dtS);
    thrustDrive(mag, g_thrust.appliedDir);
    thrustRetune(g_cfg.thrHystA, g_thrAmpsFilt, mag, g_thrust.appliedDir);

    int srvPwm = g_steer.update(g_cfg, g_angleDeg, g_feedbackOk, steerFailsafe,
                                g_srvAmpsFilt, nowMs, dtS);
    servoDrive(srvPwm);

    // --- status LED: solid on trouble, 1 Hz heartbeat otherwise ---------- //
    bool trouble =
        thrustFailsafe || steerFailsafe || !g_feedbackOk || g_steer.stalled;
    gpio_put(PIN_LED_STAT, trouble ? 1 : ((nowMs / 500) & 1));

    // --- feedback lines --------------------------------------------------- //
    if (nowMs - lastAMs >= REPORT_A_MS) {
      lastAMs = nowMs;
      int wrap = (int)(g_angleDeg / g_cfg.steerRange * 100.0f);
      if (wrap > 100) wrap = 100;
      if (wrap < -100) wrap = -100;
      char fb[VANCHOR_LINE_MAX];
      snprintf(fb, sizeof fb, "A %.1f %d %d %d", (double)g_angleDeg,
               g_feedbackOk ? 1 : 0, wrap, g_lastSeq);
      sendLine(fb, sizeof fb);
    }
    if (nowMs - lastEMs >= REPORT_E_MS) {
      lastEMs = nowMs;
      char fb[VANCHOR_LINE_MAX];
      snprintf(fb, sizeof fb, "E %d %c %s %d",
               (int)(g_thrust.applied * 255.0f + 0.5f),
               g_thrust.appliedDir < 0 ? 'R' : 'F', g_thrust.state, g_lastSeq);
      sendLine(fb, sizeof fb);
    }
  }
}

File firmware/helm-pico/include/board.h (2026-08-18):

/*
 * board.h — helm board v4.2 pin map + tuning for the on-board Pico 2.
 *
 * Pin numbers are RP2350 GPIOs; the net names match the schematic
 * (boards/helm/sheets/mcu.py) and docs/HANDOFF.md. Anything marked
 * CALIBRATE has a bench procedure in the firmware README.
 *
 * DIY / bare-Pico builds: every #define below is #ifndef-guarded, so any pin
 * or default can be overridden from the build instead of editing this file:
 *   cmake -B build -DPICO_BOARD=pico \
 *     -DCMAKE_CXX_FLAGS="-DPIN_LED_STAT=25 -DTUN_I2C_ADDR=0x42"
 * See README "Bare Pico / DIY build" for the wiring that goes with it —
 * especially the EXTERNAL pulldowns on the four EN pins: the firmware cannot
 * protect the reset/BOOTSEL window, only resistors can.
 */
#ifndef HELM_BOARD_H
#define HELM_BOARD_H

// ---------------------------------------------------------------- inputs --
#ifndef PIN_HALL_ZERO
#define PIN_HALL_ZERO      0   // HALL_ZERO: open-collector hall (J9.3), 10k
#endif
                               // pull-up + RC on board; LOW at the magnet.

// I2C0 to the SBC (PI_SDA/PI_SCL on the ribbon): line-protocol tunnel,
// slave address 0x42 — equivalent to the USB CDC port (docs/I2C-TUNNEL.md).
#ifndef PIN_PI_SDA
#define PIN_PI_SDA         4
#endif
#ifndef PIN_PI_SCL
#define PIN_PI_SCL         5
#endif

// I2C1 master -> AS5600 steering encoder (J11; 4.7k pull-ups R9/R10 on board)
#ifndef PIN_ENC_SDA
#define PIN_ENC_SDA        6
#endif
#ifndef PIN_ENC_SCL
#define PIN_ENC_SCL        7
#endif
#ifndef ENC_I2C
#define ENC_I2C            i2c1
#endif
#ifndef ENC_I2C_HZ
#define ENC_I2C_HZ         400000
#endif

// -------------------------------------------------------- servo H-bridge --
// 2x BTN8982TA on protected VIN. IN = PWM, INH = enable (100k pulldowns on
// board keep the bridge disabled whenever the Pico is dead or rebooting).
#ifndef PIN_SRV_RPWM
#define PIN_SRV_RPWM       8   // U7 IN  (drive toward +deg / starboard)
#endif
#ifndef PIN_SRV_LPWM
#define PIN_SRV_LPWM       9   // U8 IN  (drive toward -deg / port)
#endif
#ifndef PIN_SRV_R_EN
#define PIN_SRV_R_EN      10   // U7 INH
#endif
#ifndef PIN_SRV_L_EN
#define PIN_SRV_L_EN      11   // U8 INH
#endif

// ------------------------------------------------- thrust bridge on J13 --
// 8-wire cable to the companion thrust-driver board (IBT-2 pin order).
#ifndef PIN_THR_RPWM
#define PIN_THR_RPWM      12
#endif
#ifndef PIN_THR_LPWM
#define PIN_THR_LPWM      13
#endif
#ifndef PIN_THR_R_EN
#define PIN_THR_R_EN      14
#endif
#ifndef PIN_THR_L_EN
#define PIN_THR_L_EN      15
#endif

#ifndef PIN_LED_STAT
#define PIN_LED_STAT      17   // yellow LED via R13 (bare Pico: use 25 = onboard LED)
#endif

// ------------------------------------------------------------------ ADCs --
#ifndef PIN_ADC_SERVO_IS
#define PIN_ADC_SERVO_IS  26   // ADC0: servo bridge current sense
#endif
#ifndef PIN_ADC_THR_IS
#define PIN_ADC_THR_IS    27   // ADC1: thrust driver current sense (mixed R/L)
#endif
#ifndef PIN_ADC_VBAT
#define PIN_ADC_VBAT      28   // ADC2: VBAT through 47k/10k divider
#endif

#ifndef ADC_VREF_V
#define ADC_VREF_V        3.3f
#endif
// VBAT divider R11 47k / R12 10k  ->  Vbat = Vadc * 5.7
#ifndef VBAT_SCALE
#define VBAT_SCALE        ((47.0f + 10.0f) / 10.0f)
#endif
// Thrust IS: BTN8982 kILIS ~= 22700; 1k loads at the driver, 1k series +
// 20k to GND on the helm. Simulated end-to-end: ~21 mV per motor amp
// (sim/README.md). CALIBRATE against a clamp meter before trusting it.
#ifndef THR_IS_V_PER_A
#define THR_IS_V_PER_A    0.021f
#endif
// Servo IS: RAW node 1k load (R19), so ~44 mV/A before the R18/C12 filter.
#ifndef SERVO_IS_V_PER_A
#define SERVO_IS_V_PER_A  0.044f
#endif
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

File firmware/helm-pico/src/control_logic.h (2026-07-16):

/*
 * control_logic.h — hardware-free control cores for the helm Pico.
 *
 * Everything in here is pure state-machine/math with injected time and an
 * injected HelmConfig, so the host test suite (tests/) exercises the exact
 * code that ships and the CONF machinery can retune it live:
 *
 *   ThrustGate   — engine.ino semantics: reverse dead-time interlock, slew
 *                  limit, watchdog failsafe, E-line state word.
 *   SteeringLoop — steering.ino semantics: PID + deadband + stiction floor +
 *                  stall detection + watchdog hold, on an encoder angle.
 *   EncoderUnwrap— AS5600 12-bit raw -> continuous multi-turn angle.
 *
 * The protocol constants (watchdog window etc.) come from the vendored
 * vanchor_protocol.h so firmware and contract cannot drift apart.
 */
#ifndef HELM_CONTROL_LOGIC_H
#define HELM_CONTROL_LOGIC_H

#include <math.h>
#include <stdint.h>

#include "board.h"
#include "config.h"

// ------------------------------------------------------------------------ //
// Thrust: reverse gate + slew (port of engine.ino, output-stage agnostic)
// ------------------------------------------------------------------------ //
struct ThrustGate {
  float applied = 0.0f;      // 0..1 magnitude currently at the bridge
  int8_t appliedDir = +1;    // +1 F, -1 R — direction the bridge is set to
  uint32_t zeroSinceMs = 0;  // when |applied| last fell to ~0 (0 = "not yet")

  const char *state = "RUN"; // E-line state word for the last update

  // One control tick. wantMag/wantDir are the *requested* throttle; failsafe
  // forces a slewed stop without flipping direction (engine.ino behaviour).
  // Returns the magnitude to output; appliedDir is the direction to output.
  float update(const HelmConfig &cfg, float wantMag, int8_t wantDir,
               bool failsafe, uint32_t nowMs, float dtS) {
    if (failsafe) {
      wantMag = 0.0f;
      wantDir = appliedDir;  // never flip while blind; just stop
    }
    if (wantMag < 0.0f) wantMag = 0.0f;
    if (wantMag > 1.0f) wantMag = 1.0f;

    // --- reverse dead-time interlock -------------------------------------
    bool nearZero = (applied <= THR_ZERO_EPS);
    if (nearZero) {
      if (zeroSinceMs == 0) zeroSinceMs = nowMs ? nowMs : 1;
    } else {
      zeroSinceMs = 0;
    }
    float allowed = wantMag;
    if (wantDir != appliedDir) {
      if (!nearZero) {
        allowed = 0.0f;                       // spin down first
      } else if (zeroSinceMs == 0 ||
                 (nowMs - zeroSinceMs) < (uint32_t)cfg.thrRevMs) {
        allowed = 0.0f;                       // rest at zero, keep waiting
      } else {
        appliedDir = wantDir;                 // safe to flip now
      }
    }

    // --- slew limit -------------------------------------------------------
    float maxStep = cfg.thrSlew * dtS;
    float delta = allowed - applied;
    if (delta > maxStep) delta = maxStep;
    if (delta < -maxStep) delta = -maxStep;
    applied += delta;
    if (applied < 0.0f) applied = 0.0f;
    if (applied > 1.0f) applied = 1.0f;

    state = failsafe                        ? "FAILSAFE"
            : (allowed < wantMag - 0.001f)  ? "REVDELAY"
            : (applied + 0.001f < allowed)  ? "SOFTSTART"
                                            : "RUN";
    return applied;
  }
};

// ------------------------------------------------------------------------ //
// Thrust PWM frequency schedule (boards/thrust-driver/README.md)
// ------------------------------------------------------------------------ //
// Piecewise-linear current -> frequency, with hysteresis applied by the
// caller (only retune when the ideal frequency moved by more than the band).
static inline float thrustFreqHzForAmps(float amps) {
  static const float A[] = {0, 5, 10, 15, 20, 25, 30, 40, 50};
  static const float K[] = {16, 16, 12, 8, 6, 5, 4, 3, 2};  // kHz
  const int n = sizeof(A) / sizeof(A[0]);
  if (amps <= A[0]) return K[0] * 1000.0f;
  for (int i = 1; i < n; i++) {
    if (amps <= A[i]) {
      float t = (amps - A[i - 1]) / (A[i] - A[i - 1]);
      return (K[i - 1] + t * (K[i] - K[i - 1])) * 1000.0f;
    }
  }
  return K[n - 1] * 1000.0f;
}

// ------------------------------------------------------------------------ //
// AS5600 raw counts -> continuous angle (multi-turn unwrap)
// ------------------------------------------------------------------------ //
struct EncoderUnwrap {
  int32_t accum = 0;       // continuous counts since boot
  uint16_t prevRaw = 0;
  bool primed = false;

  void feed(uint16_t raw12) {
    raw12 &= 0x0FFF;
    if (!primed) {
      prevRaw = raw12;
      primed = true;
      return;
    }
    int16_t d = (int16_t)(((raw12 - prevRaw + ENC_COUNTS_PER_REV / 2) &
                           (ENC_COUNTS_PER_REV - 1)) -
                          ENC_COUNTS_PER_REV / 2);
    accum += d;
    prevRaw = raw12;
  }

  // Continuous azimuth degrees relative to `zeroAccum` counts.
  float degrees(const HelmConfig &cfg, int32_t zeroAccum) const {
    float revs = (float)(accum - zeroAccum) / (float)ENC_COUNTS_PER_REV;
    float deg = revs * 360.0f / cfg.encGear;
    if (cfg.encInvert >= 0.5f) deg = -deg;
    return deg;
  }
};
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

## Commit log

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2026-07-01 chore: bootstrap KiCad project skeleton (ERC 0, DRC only missing-outline)
    [vanchor-helm.kicad_pcb, vanchor-helm.kicad_sch]
2026-07-01 feat: all five schematic sheets + root, ERC 0 errors, netlist gate PASS
    - netlist-style sheets generated from python net specs (sheets/*.py)
    - 94 nets / 334 pins; key-net pin-count check in scripts/check_nets.py
    - ERC waivers documented in hardware/ERC-notes.md
    [mcu.kicad_sch, pi.kicad_sch, power.kicad_sch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]
2026-07-01 feat: custom footprints (Pololu buck, Pico+SWD), Pi-reflashable Pico via SWD on GPIO24/25
    [mcu.kicad_sch]
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2026-07-01 feat: on-board 800W H-bridge (HIP4082 + 8 FET, ACS758, M5 lugs) + BTN8982 servo bridge; 160x120 board, placement DRC-clean
    [mcu.kicad_sch, power.kicad_sch, servo.kicad_sch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]
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2026-07-01 feat: pre-laid power spine tracks + BASE_GND flag + GND stitching in import
    [vanchor-helm.dsn, vanchor-helm.kicad_pcb]
2026-07-02 feat: routed board via scripted freerouting pipeline (T10) — known GUI touch-up items documented
    [power.kicad_sch, thrust.kicad_sch, vanchor-helm.dsn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]
2026-07-02 feat: fab outputs — gerbers, drill, BOM w/ MPN, schematic PDF, renders (T11)
    [vanchor-helm-B_Cu.gbl, vanchor-helm-B_Mask.gbs, vanchor-helm-B_Paste.gbp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]
2026-07-02 feat: v2 board 200x150mm — DRC clean, zero touch-up (fresh layout, 2x spacing)
    [vanchor-helm.dsn, vanchor-helm.kicad_pcb]
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2026-07-02 cost pass 10 (schematic): remove on-board H-bridge, add J13 external-driver header (IBT-2 pinout); ERC 0, gate PASS
    [mcu.kicad_sch, pi.kicad_sch, power.kicad_sch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]
2026-07-02 cost passes 5-9: audits + cost-driver analysis + variant notes (docs/cost-optimization-log.md); v3 board script 150x120
    [vanchor-helm.dsn, vanchor-helm.kicad_pcb]
2026-07-02 feat: v3 cost-optimized board (pass 10) — 150x120 1oz, external thrust driver on J13, DRC clean
    [vanchor-helm.kicad_pcb]
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2026-07-02 feat: v3.1 12V-only — generic 5V buck module on J14, U5/U6/J17 removed, SMCJ18A TVS, servo direct on VIN; DRC clean
    [mcu.kicad_sch, power.kicad_sch, servo.kicad_sch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]
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2026-07-02 feat: v4 Orange Pi Zero 3 carrier — 125x95mm, 26-pin socket, module-on-top, DRC clean
    [pi.kicad_sch, vanchor-helm.dsn, vanchor-helm.kicad_pcb]
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2026-07-02 feat: v4.1 — J1 male header for 26-way IDC ribbon (pre-soldered Zero 3), J1.14/J2.9 NC by design, clearance 0.14; DRC clean
    [pi.kicad_sch, vanchor-helm.dsn, vanchor-helm.kicad_pcb]
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2026-07-02 chore: Mouser single-source order file + J1 MPN fix
    [mouser-order.csv]
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2026-07-02 chore: mouser order v6 — buck moved to the AliExpress order (XL4015)
    [mouser-order.csv]
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2026-07-02 fix: F2 footprint MF-RG300 (was oversized RG400, body offset); feat: readable 2-page schematic (carrier/control merged specs)
    [carrier.kicad_sch, control.kicad_sch, mcu.kicad_sch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]
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2026-07-02 feat: silkscreen connection legends (connector purposes, J13 pin order, J14 pin labels, polarity marks)
    [vanchor-helm-B_Cu.gbl, vanchor-helm-B_Mask.gbs, vanchor-helm-B_Paste.gbp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]
2026-07-02 wip: v4.2 XL4015 daughterboard (pre-lays, ENC parts near J11, tab straps) + thrust-driver spec & net-spec draft
    [carrier.kicad_sch, vanchor-helm.dsn, vanchor-helm.kicad_pcb]
2026-07-02 feat: v4.2 XL4015 buck daughterboard (U5 slotted pads, pre-laid 5V/UART5 spans, ENC parts at J11) — DRC clean
    [vanchor-helm-B_Cu.gbl, vanchor-helm-B_Mask.gbs, vanchor-helm-B_Paste.gbp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]
2026-07-02 refactor: repo restructure — hardware/ -> boards/helm/ (multi-board layout for the thrust driver)
    [carrier.kicad_sch, control.kicad_sch, mouser-order.csv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]
2026-07-02 feat: thrust-driver board — 12-24V BTN8982 H-bridge, DRC clean (0 errors / 0 unconnected)
    - J1 mirrors helm J13 1:1 (straight 8-wire cable)
    - base variant U1+U2 (~30A), high-power adds U3/U4 DNP pair (~50A)
    - exposed solder lanes on all power paths for copper-braid reinforcement
    - fab outputs: gerbers zip, BOM, schematic PDF, renders
    [driver.kicad_sch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]
2026-07-02 feat(helm): J2 doubles as Raspberry Pi port (classic 26-pin positions), silk + docs
    The PI26 net map already follows the classic RPi 26-pin layout, so a
    Raspberry Pi (40-pin header pins 1-26) drops onto J2 via the same 26-way
    IDC ribbon: power, Pico I2C link (SDA1/SCL1), console UART (TXD0/RXD0),
    SPI and SWD/RUN GPIOs all line up. Fit one SBC only; J4 'UART2' JST is
    bit-bang-only on an RPi (pins 11/13 are plain GPIOs there).
    [carrier.kicad_sch, vanchor-helm.kicad_pcb]
2026-07-02 feat(helm): NMEA2000/CAN provision — J5 power/shield connector, VIN tap, CAN-on-J12 docs
    CAN rides the Pico 2 (can2040 on GP18/GP19); a 3.3V transceiver module
    (Waveshare SN65HVD230) plugs J12 pins 1/8/6/7. New J5 XH-3 lands the N2K
    drop cable's V+/GND/SHIELD; R41 (0R DNP) optionally powers the backbone
    from VIN, R42 (0R DNP) bonds shield to GND. DRC 0/0.
    [carrier.kicad_sch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]
2026-07-02 feat(thrust-driver): NMEA2000 smart-node provision — DNP Pico 2 + CAN/N2K connectors, board 95x92
    Unpopulated through-hole provision to run the bridge as a standalone N2K
    node: U5 Pico 2 (GP12-15 parallel to J1 drive nets, GP26/27 ADC sense via
    R12/R13 1k, GP18/19 CAN), U6 SIP-3 5V reg from VBAT, J6 transceiver
    header (3V3/GND/TX/RX), J7 N2K V+/GND/SHIELD with 0R power-tap/shield
    options. Board grew 75->92mm; existing routing untouched; DRC 0 errors /
    0 unconnected (solder-lane mask apertures set to ignore by design).
    [driver.kicad_sch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]
2026-07-02 docs: datasheet audit corrections — BTN8982 kILIS 22.7k (not 8500), node ADC fault-mode guidance, R-78HE for 24V, XL4015 variant note
    [mcu.py]
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2026-07-04 feat(helm): steering-zero hall sensor input — J9 grows to 1x3 (5V/GND/SIG), 10k pullup + RC into Pico GP0
    Open-collector hall switch (A3144 class) sees a magnet at servo center;
    GP0 reads it (also broken out on J12.2; UART0 fallback = GP16/GP1).
    Pour-redundant freerouted GND returns near J9/J10 removed. DRC 0/0.
    [carrier.kicad_sch, control.kicad_sch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]
2026-07-04 fix(helm): F2 polyfuse sits straight — custom MF-R250 footprint with in-line 5.1mm pads (KiCad's Bourns fps are stagger-lead), pour-redundant GND returns cleared. DRC 0/0
    [carrier.kicad_sch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]
2026-07-05 test: ngspice simulation suite for all analog chains — IS telemetry, VBAT sense, reverse-FET, hall input, servo IS (all PASS, plots + firmware scaling numbers)
    [hall_tran.csv, is_dc.csv, servo_ac.csv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]
2026-07-15 docs(schematics): readable layouts — un-stack N2K cluster/flags/hall trio on helm, rotate BAT54S clamps so labels clear the symbols, full driver-sheet reflow (rows, DNP node parts, pico clear of titl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
    [carrier.kicad_sch, control.kicad_sch, driver.kicad_sch]
2026-07-15 fix(gen_sheet): reference/value text offset scales with symbol extent — no more value text on tall connectors' pins (J12/J13/2x13 headers/Pico)
    [carrier.kicad_sch, control.kicad_sch, driver.kicad_sch]
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2026-07-15 fix(helm): R41/R42 N2K option links are now hand-solderable THT vertical axials (were 0805); R41.2 lands directly in the VIN trunk
    [carrier.kicad_sch, mouser-order.csv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]
2026-07-16 feat(gen_sheet): drawn wires + power rails (WIRES/RAILS spec lists) with per-cluster label dedup; wire up power chain, VIN rail, N2K links, sense rails, SR/LED chains
    [carrier.kicad_sch, control.kicad_sch, driver.kicad_sch]
2026-07-16 feat(schematics): wire the Pico to its peripherals on both boards
    Helm control page: GP0-3 bus to J12, 4-wire thrust bus to J13 (nested
    staircase under the pico), RPWM/LPWM to the servo bridge inputs,
    LED_STAT to R13, VBAT_SENSE over the arrivals down to the divider rail.
    Driver page: DNP-pico CAN pair to J6, IS-to-ADC series R12/R13.
    gen_sheet.py: turtle-style waypoint routing for WIRES (("x"/"y", v)
    segments + auto-L tail); layout shuffle so J12/J13 flank the pico.
    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
    [carrier.kicad_sch, control.kicad_sch, driver.kicad_sch]
2026-07-16 feat(schematics): wire the support clusters — THR_IS rail, encoder->J11, servo->J22, LED chains, VIN/VBAT rail extensions
    Control: THR_IS rail joins R38/C21/R15/R16 under J13's conditioning row;
    R20/R21 moved beside J11 and wired to it; J22 moved beside the bridges,
    U7/U8 OUT wired to it (pin-correct); U8 IS wired to the R18 divider;
    LED_STAT chain re-landed left of the pico; D6 clamp joined to the
    VBAT_SENSE rail. Carrier: R2->LED1 chain drawn, D4+R2 hang off the VIN
    rail; both LEDs rotated so the wire meets pin 2.
    Netlist verified byte-identical to the previous revision (drawing only).
    Claude-Session: https://claude.ai/code/session_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
    [carrier.kicad_sch, control.kicad_sch]
2026-07-16 fix(schematics): visual QA pass — text collisions and wire-through-symbol
    gen_sheet: BAT54S ref+value stack below the part (COM pin label owns the
    space above — fixes D8/D10/D11/D14 overprinted refs); REF_POS per-part
    ref override. Carrier: F1->Q1 drain wire enters from above instead of
    through the FET symbol; Q1 ref moved clear. Control: R20/R21 spread so
    their texts don't merge; D14 lifted off the VBAT wire; LED_STAT run
    raised above the pico power flags. Driver: ADC wires lose their dead-end
    spurs; CAN lanes dropped below the DNP value texts; D2 horizontal (label
    was overprinting ref/value). HANDOFF: waive note for the 3 paralleled-OUT
    ERC errors. Netlists verified identical on both b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
    [carrier.kicad_sch, control.kicad_sch, driver.kicad_sch]
2026-07-16 feat(schematic): draw the pico CAN pair (GP18/19) to J12
    Over-the-top route down the left margin into J12 pins 6/7; VBAT_SENSE
    corridor moved right (x208.28) to clear the new risers. Netlist identical.
    Claude-Session: https://claude.ai/code/session_011PT4Xv5KGhDdDc8nqJyMxJ
    [control.kicad_sch]
2026-07-16 feat(firmware): helm-board Pico 2 firmware — vanchor serial contract, no N2K
    One Pico replaces both vanchor-ng Arduinos over a single USB-CDC port:
    CMD/STEERD/THRUST in, A/E + CRC-8 out (contract vendored verbatim from
    vanchor-ng firmware/common). Thrust mirrors engine.ino (slew, reverse
    dead-time, failsafe states) driving J13 with the current-adaptive PWM
    schedule; steering mirrors steering.ino PID/stall/hold on an AS5600
    multi-turn angle with hall re-zeroing on GP0. 800ms protocol watchdog +
    2s hardware watchdog + enables-low-until-first-command. Host test suite
    replays the golden protocol vectors through the shipped headers (both
    CRC modes) and unit-tests the control cores — all passi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
    [board.h, control_logic.h, main.cpp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]
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2026-07-16 feat(firmware): runtime config over serial — CONF/CONFW/CONFSAVE/CONFDUMP
    All tuning constants become runtime-tunable defaults: CONF sets RAM only,
    CONFW write-throughs a single key, CONFSAVE persists the active config.
    Storage = last 4kB flash sector, magic+version+count+CRC32, append-only
    key layout; every write is diff-guarded (byte-identical image -> no
    erase) and rate-limited (2s). Values validate against per-key ranges on
    set AND on load. Replies as CRC'd 'C ...' lines the Pi ignores; config
    traffic never feeds the motor watchdog. README documents the commands
    and the flash-wear/stall dangers in detail. Host suite extended: config
    round-trip, diff primitive, corruption/version safety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
    [board.h, config.h, control_logic.h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]
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2026-07-18 docs: research — firmware/electronics lessons from ArduPilot and pypilot
    What they do, what we already match, and a prioritized punch list:
    A/B config sectors, fault-flags vocabulary + directional stall inhibit,
    watchdog forensics, asymmetric slew/dwell shaping, Pi-side line logging,
    and rev-2 board items (NTC, endstop inputs, EMI notes).
    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
2026-08-18 fix(firmware): safety + protocol hardening from the 3-lens review; RP2040/DIY support (#1)
    Three parallel reviews (safety/control, protocol/tunnel, build/portability)
    over the helm-pico firmware. Everything traced to file:line and regression-
    tested on the host suite (both CRC modes, ASan/UBSan clean).
    Safety:
    - PER-CHANNEL watchdogs. One shared timestamp let a live STEERD stream mask
    a dead THRUST writer: prop stuck at the last pwm forever. Each channel now
    has its own 800 ms failsafe, restoring the per-board guarantee the two-
    Arduino system had.
    - AS5600: ML (magnet-too-weak) now fails the sample; 3-sample debounce both
    directions kills single-transaction ok-chatter; a >45 deg/2m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
    [board.h, config.h, i2c_tunnel.cpp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]
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
